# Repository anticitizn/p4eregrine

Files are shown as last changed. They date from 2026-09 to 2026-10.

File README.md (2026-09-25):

# P4eregrine
An all-in-one drone ESC, flight controller and video processor, powered by an ESP32 P4 in a 40x40 mm footprint.

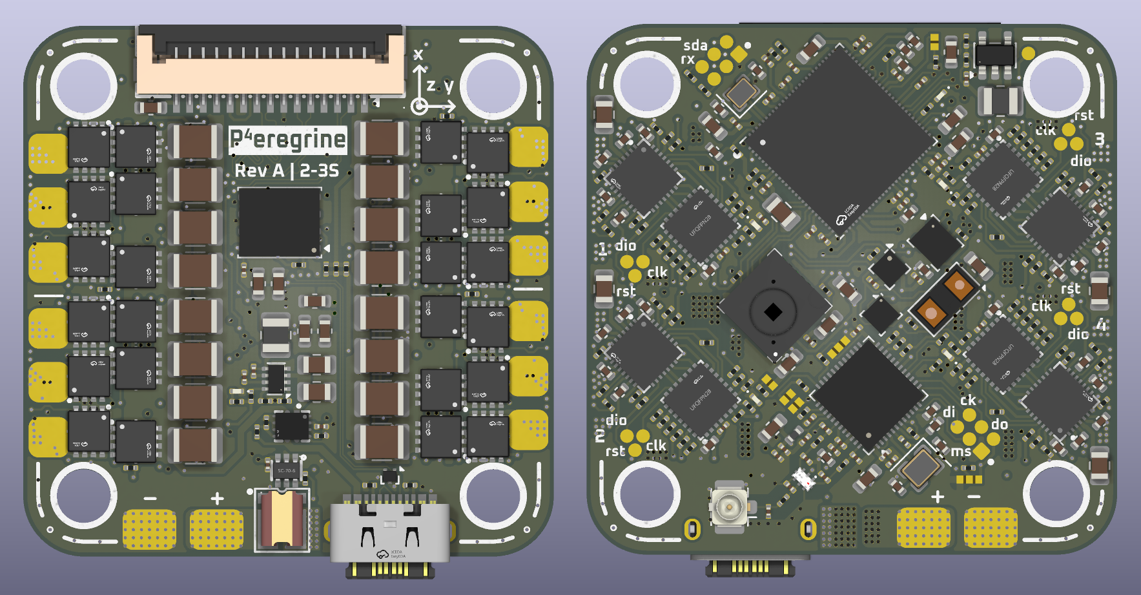
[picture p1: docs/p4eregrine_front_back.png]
Front and back PCB render


### Specifications
- 2S-3S (7-13 V) battery input
- 40x40 mm board size, 30.5x30.5 mm mounting holes
- ESP32 P4 flight computer and video processor
- ESP32 C5 for 2.4 GHz and 5 GHz Wi-Fi connectivity
- Raspberry Pi camera-compatible connector (MIPI-CSI)
- LSM6DSR IMU
- LIS2MDL magnetometer
- LPS22HB barometer
- VL53L1X time of flight sensor
- PMW3901MB optical flow sensor
- STM32G071GBU6 + DRV8328 for each ESC running AM32, hopefully capable of handling 15 A current per motor
- JMSL0302AU MOSFETs (the cheapest semi-reputable 3x3 package I could find with a lower than 3 mOhm RDS(on) when hot)
- TPS62933 buck converter for 3.3V power, capable of continuously supplying ~2.3 A
- Single high-side current measurement shunt for the entire board

### Stackup
6 layers, 1oz outer copper, 0.5 oz inner copper, 1.2 mm thick (JLC06121H-3313)
- L1: Mixed
- L2: GND
- L3: 3V3 plane + some signals
- L4: BAT plane + some signals
- L5: GND
- L6: Mixed

Filled and capped vias are a must, as the board makes extensive use of via-in-pad. All vias are 0.45/0.25 mm or bigger to avoid incurring extra fees from JLCPCB.

Schematics, layer images and BOM are available in `docs/`, Gerber files in `export/`.

### Software?
AM32 for the ESCs, custom firmware for the rest. I have most parts working on the previous prototype (ESP32 S3 with 8520 brushed motors)

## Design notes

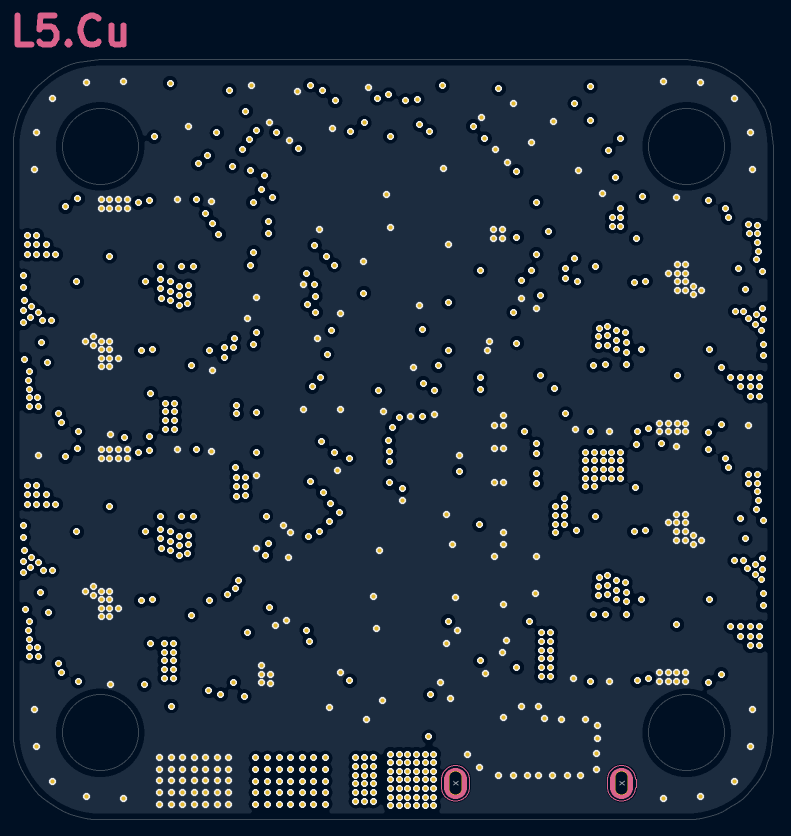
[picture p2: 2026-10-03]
docs/l5.png

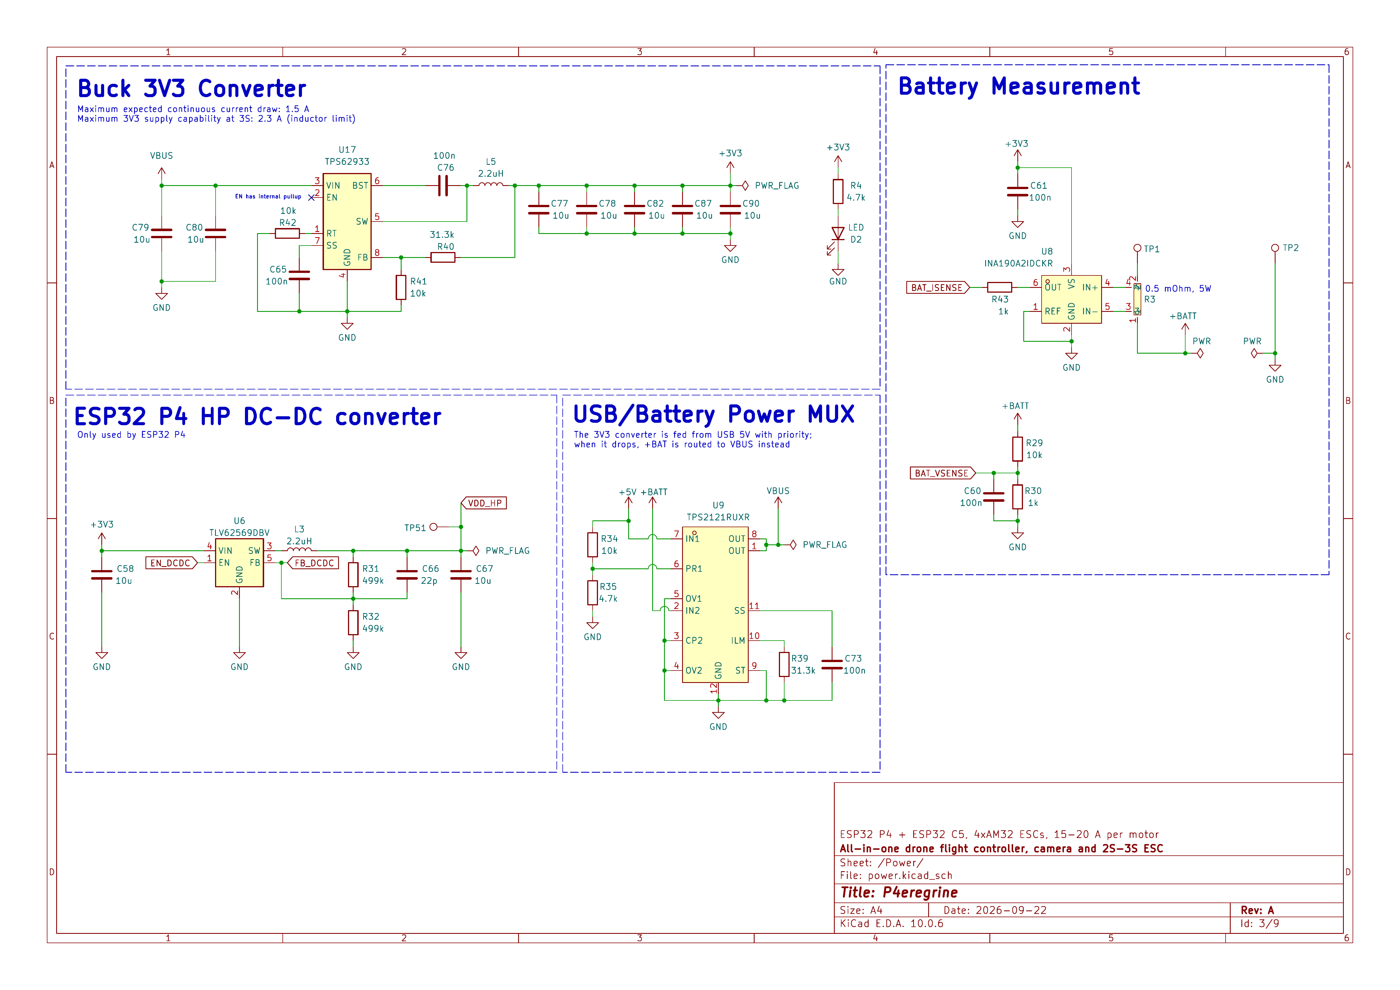
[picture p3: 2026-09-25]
docs/p4eregrine_rev_a-3.png

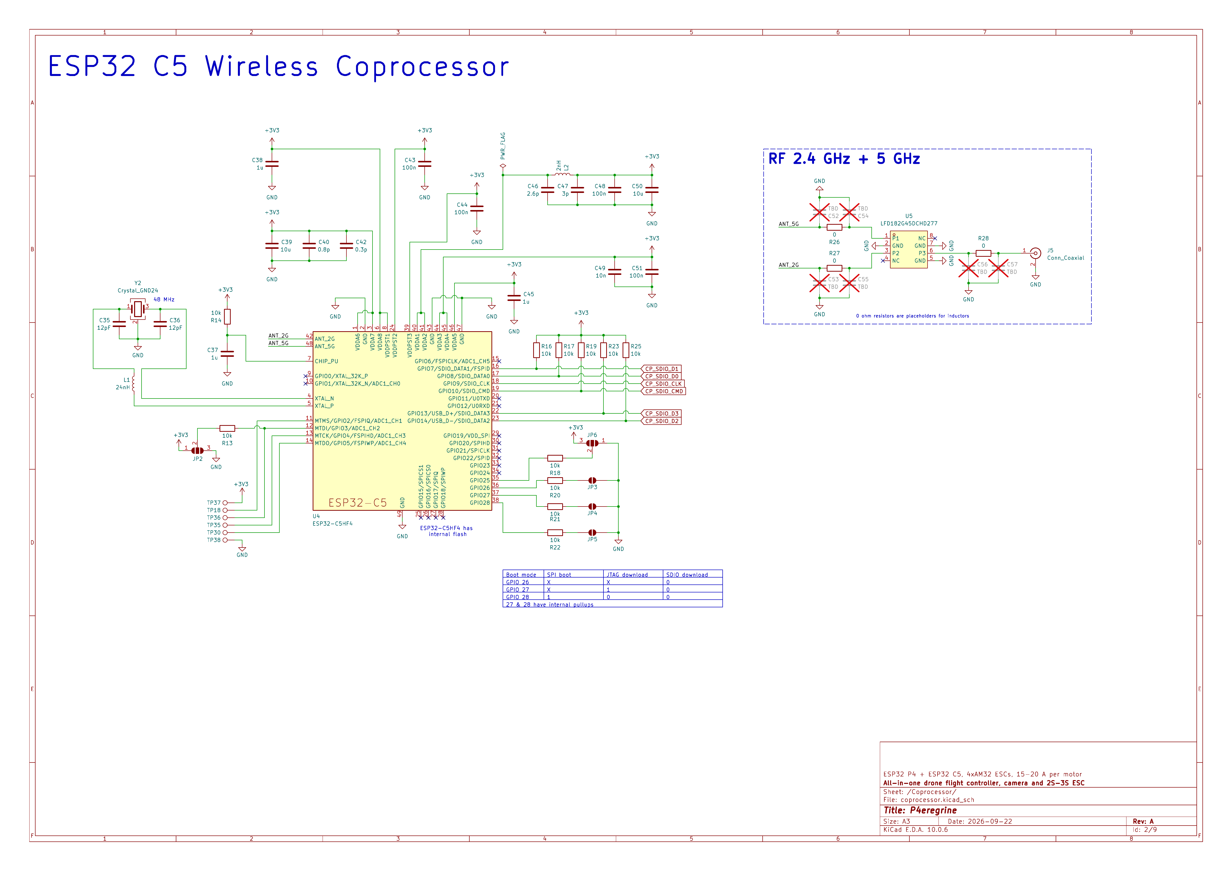
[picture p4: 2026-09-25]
docs/p4eregrine_rev_a-2.png

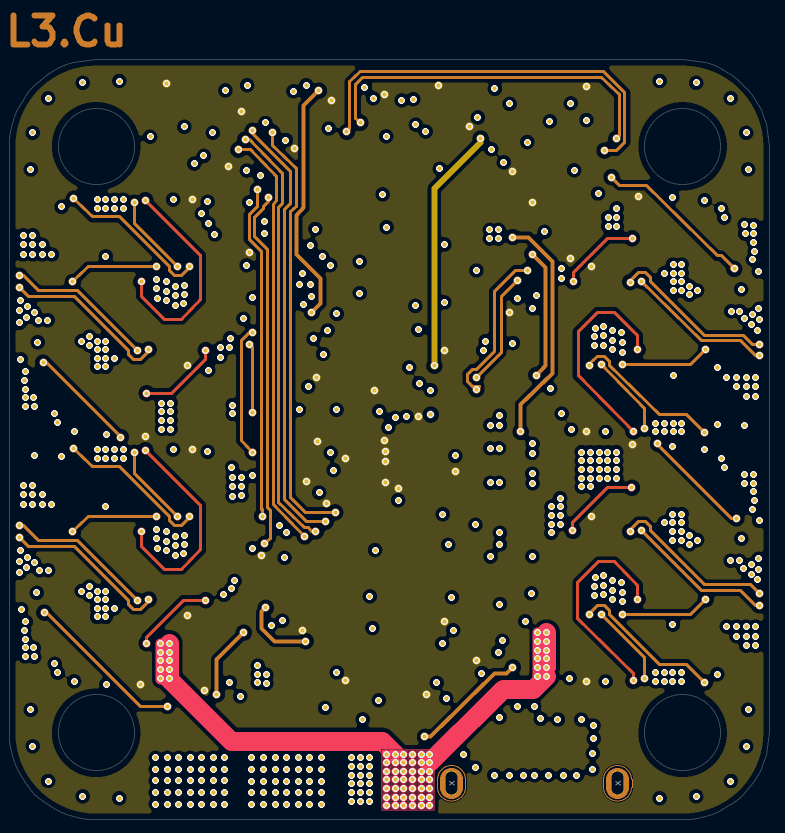
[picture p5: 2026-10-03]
docs/l3.png

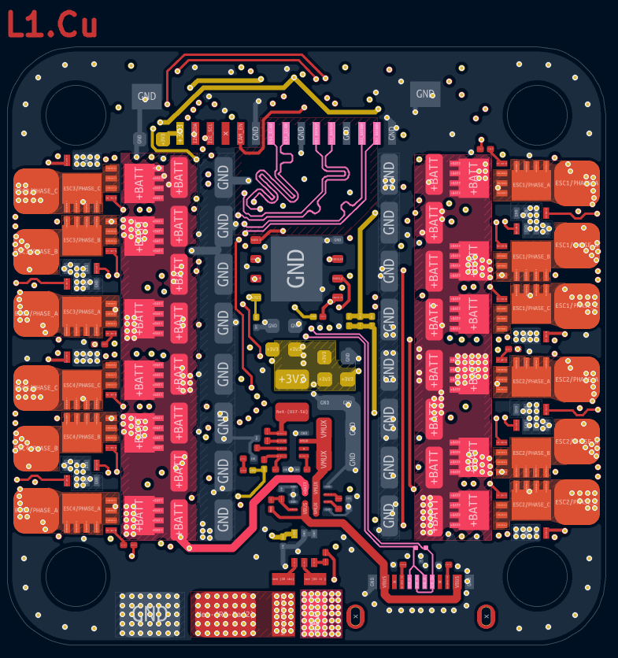
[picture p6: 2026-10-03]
docs/l1.png

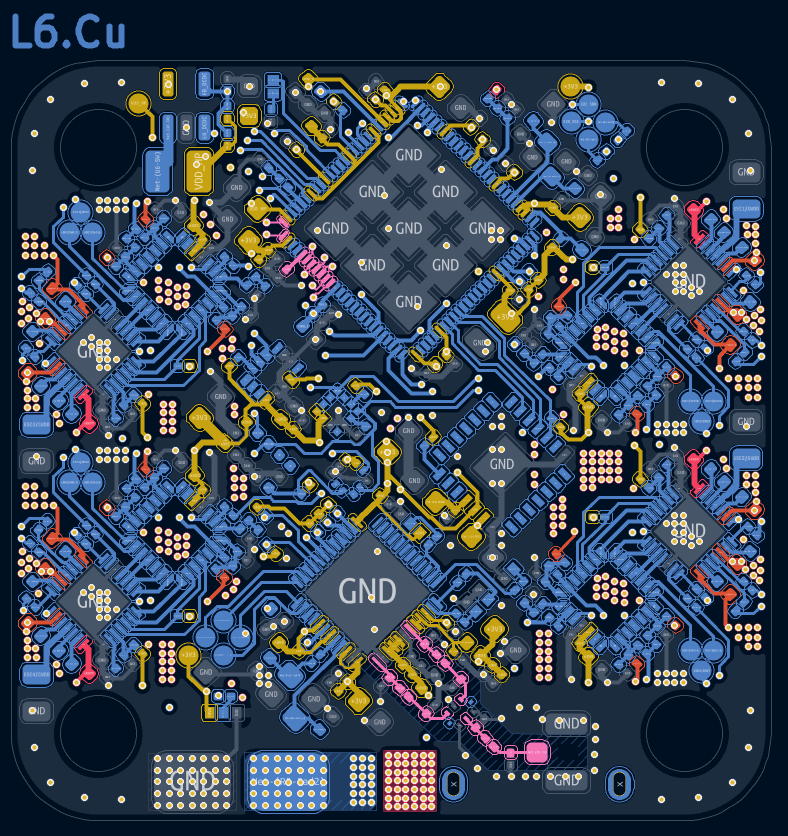
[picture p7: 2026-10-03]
docs/l6.png

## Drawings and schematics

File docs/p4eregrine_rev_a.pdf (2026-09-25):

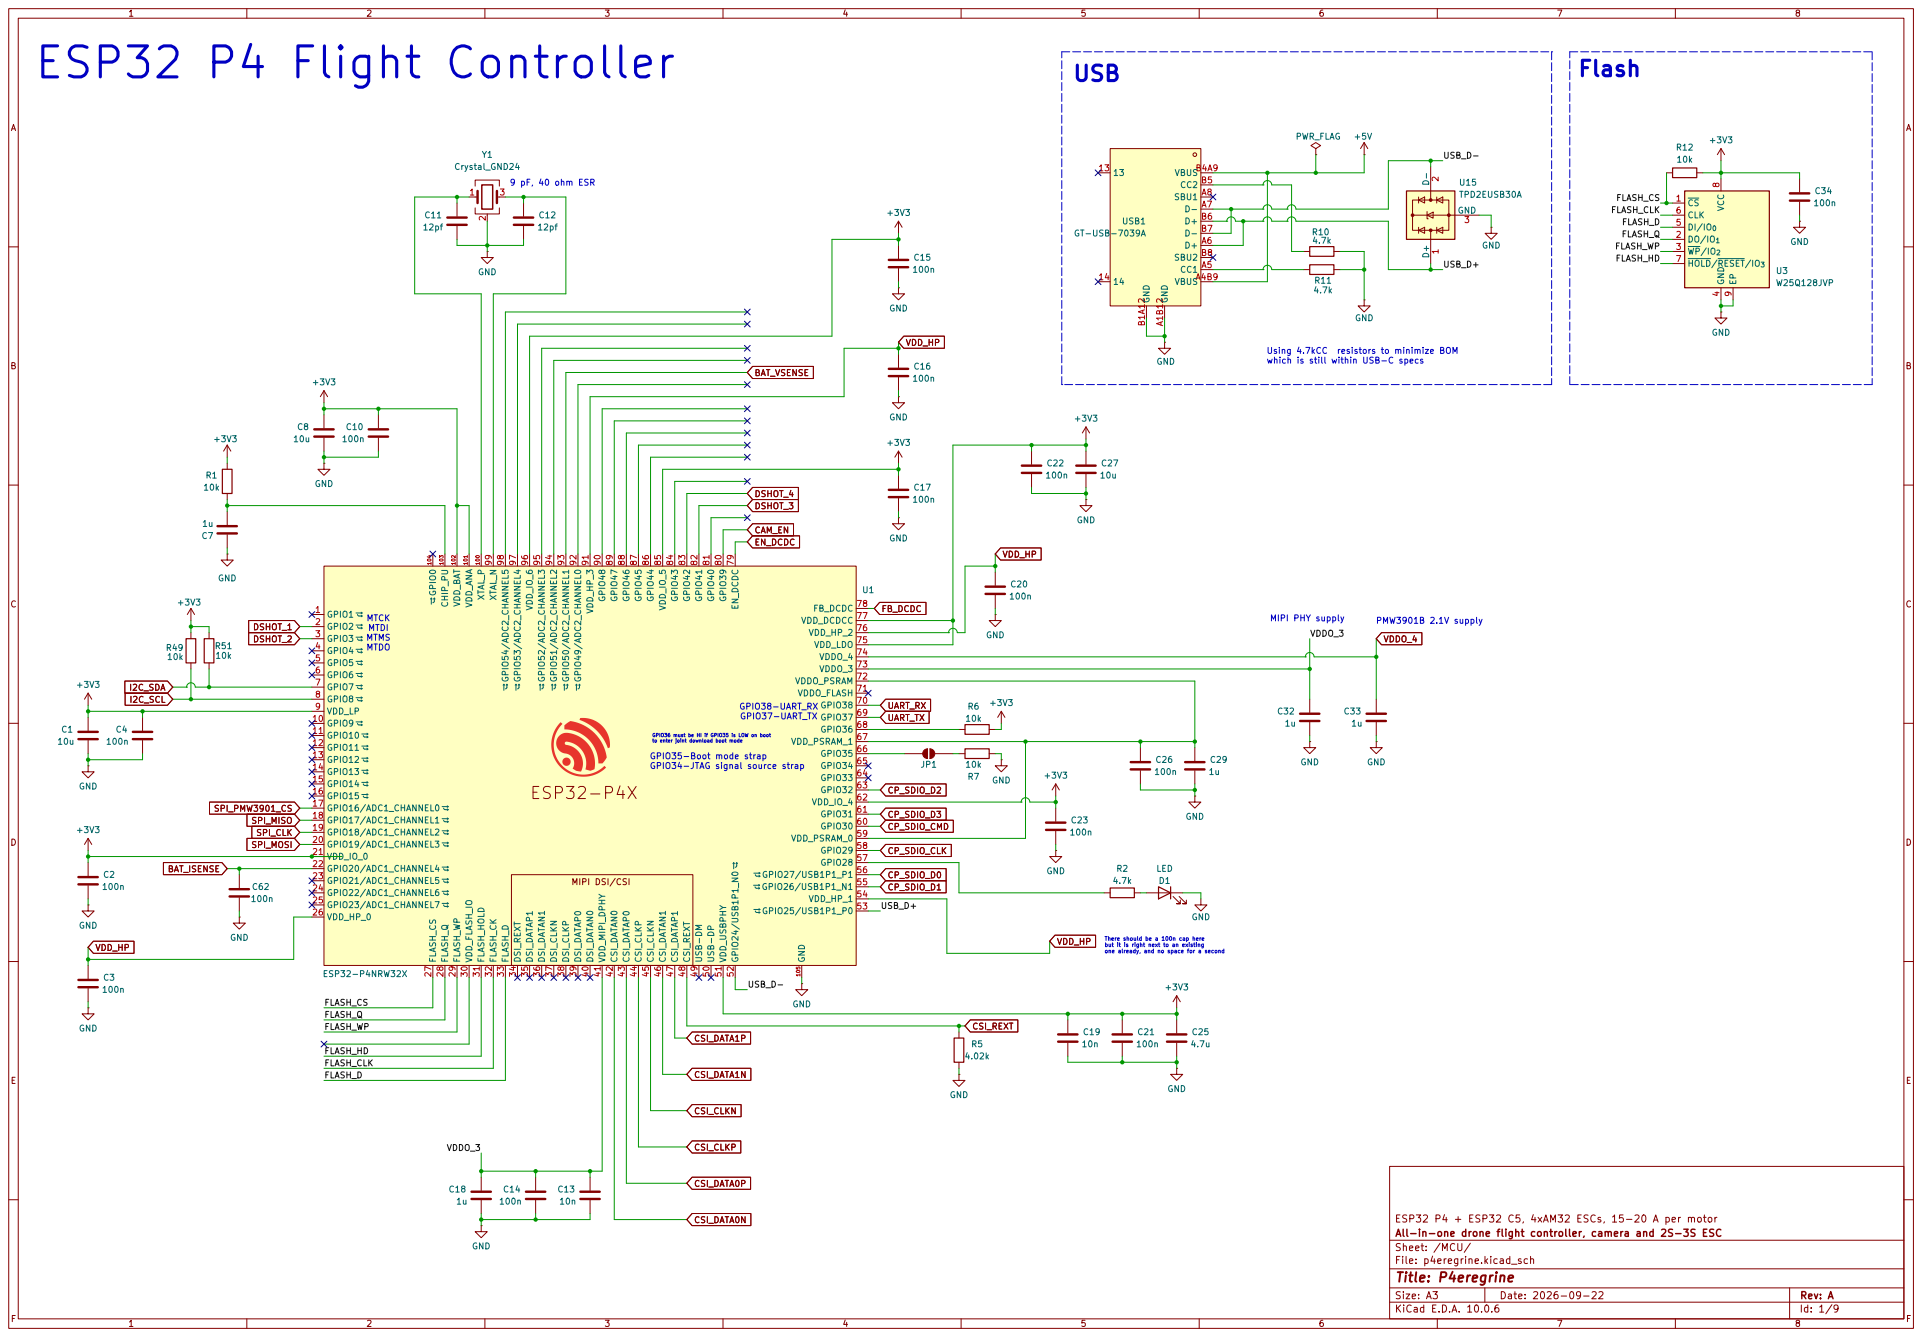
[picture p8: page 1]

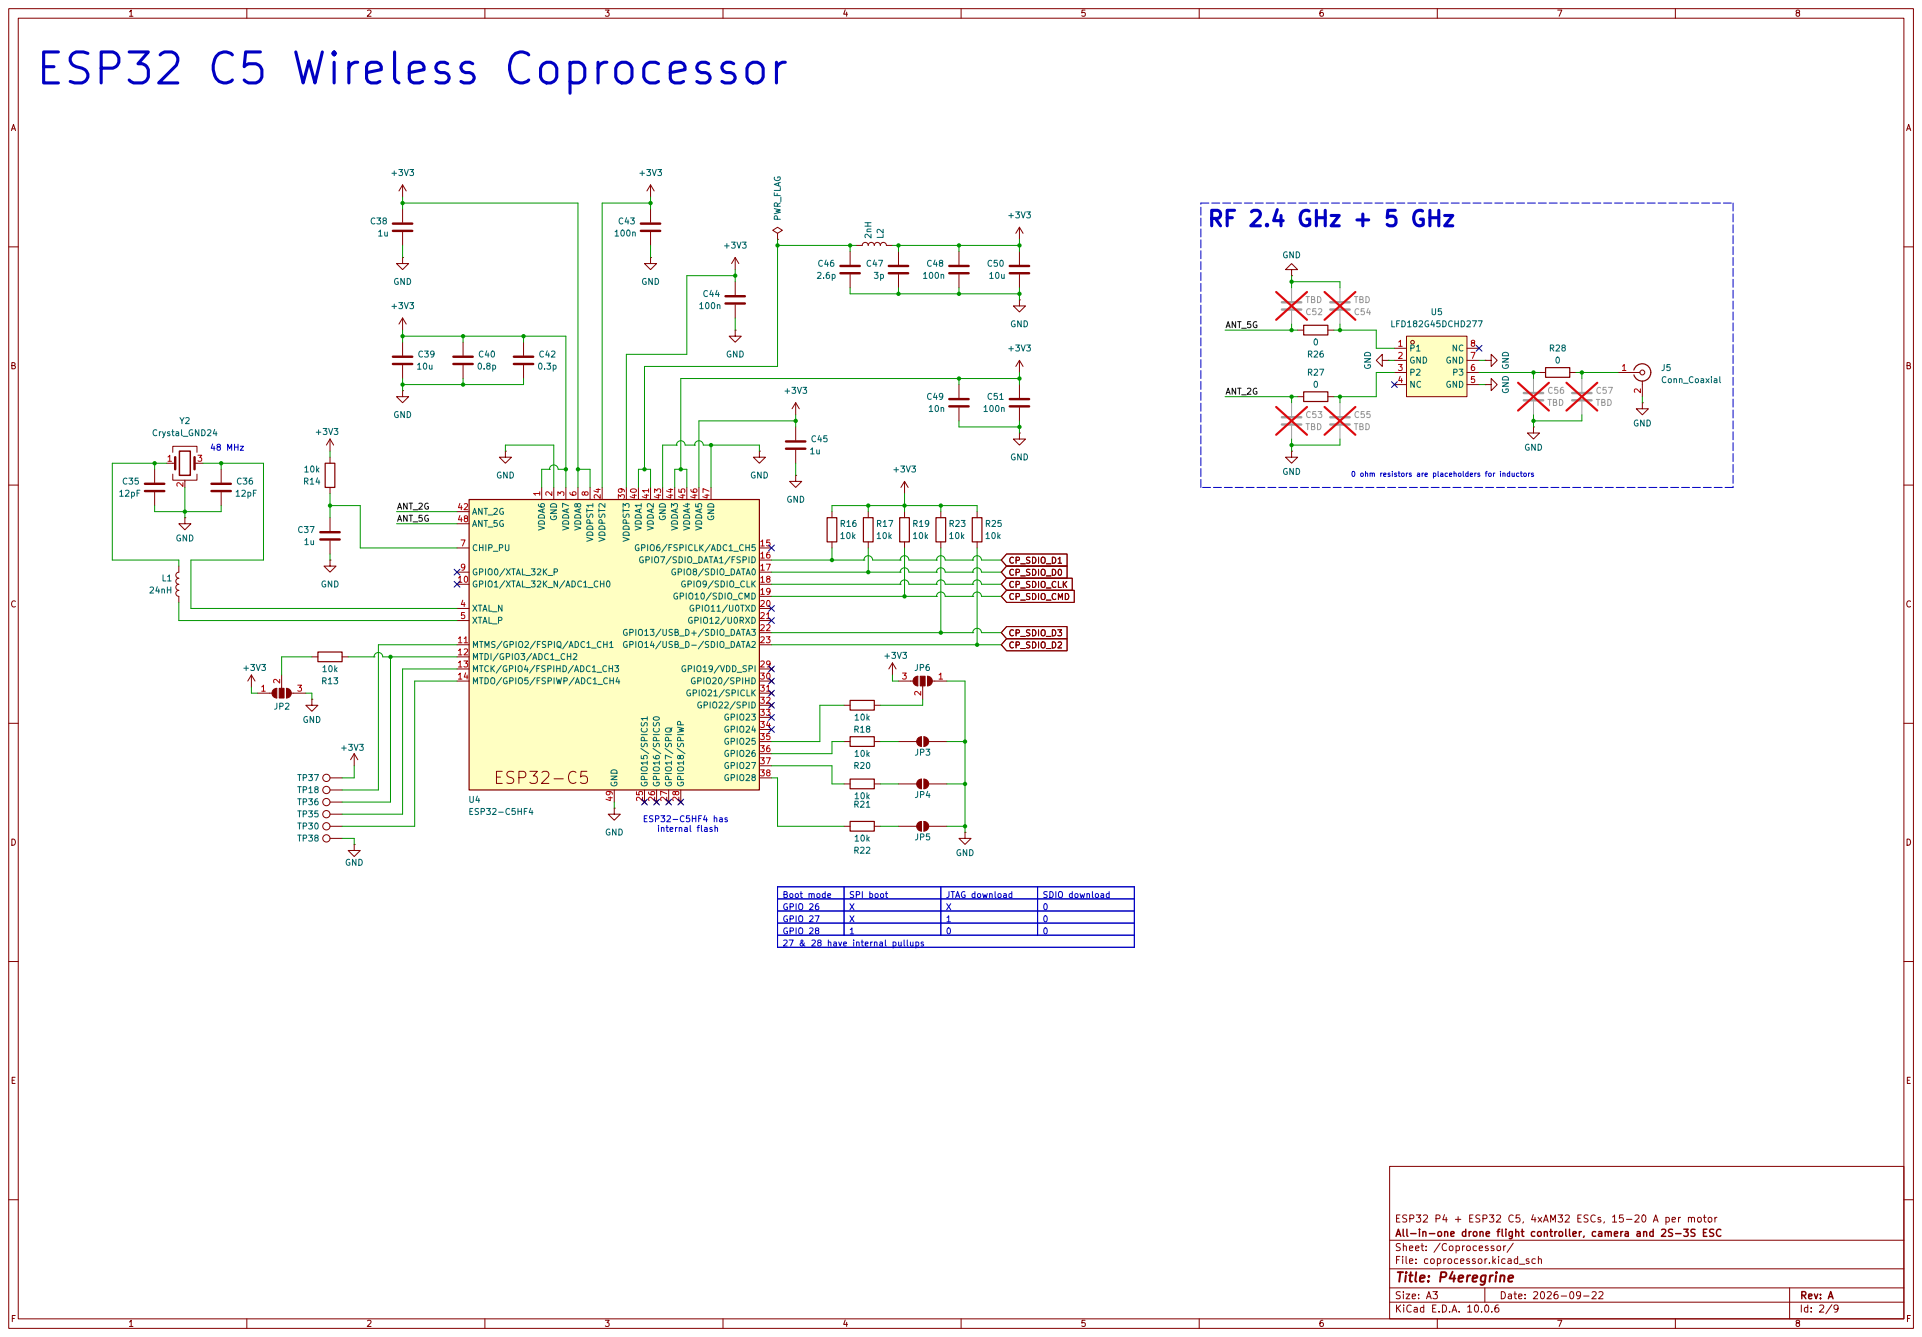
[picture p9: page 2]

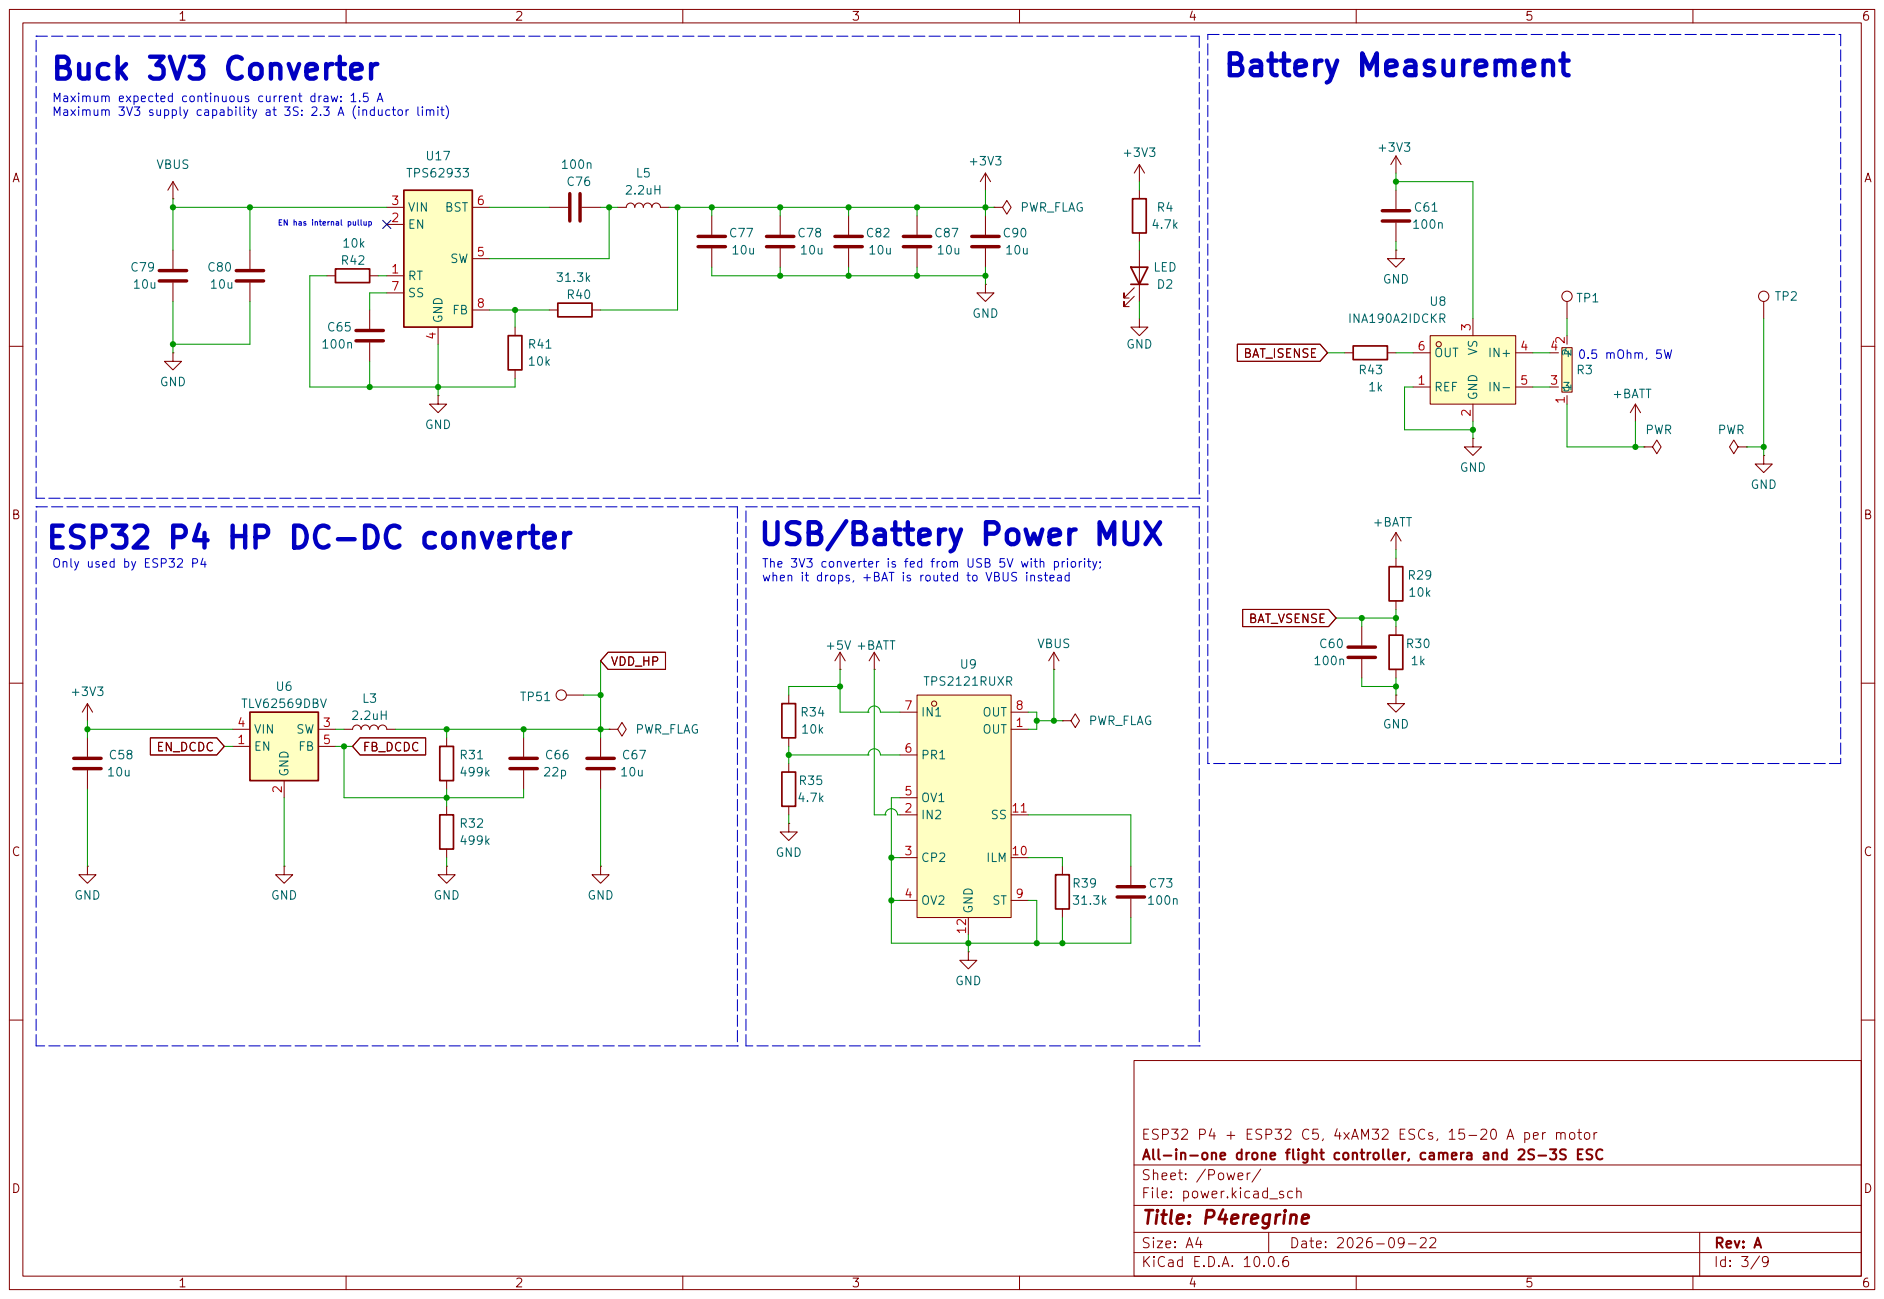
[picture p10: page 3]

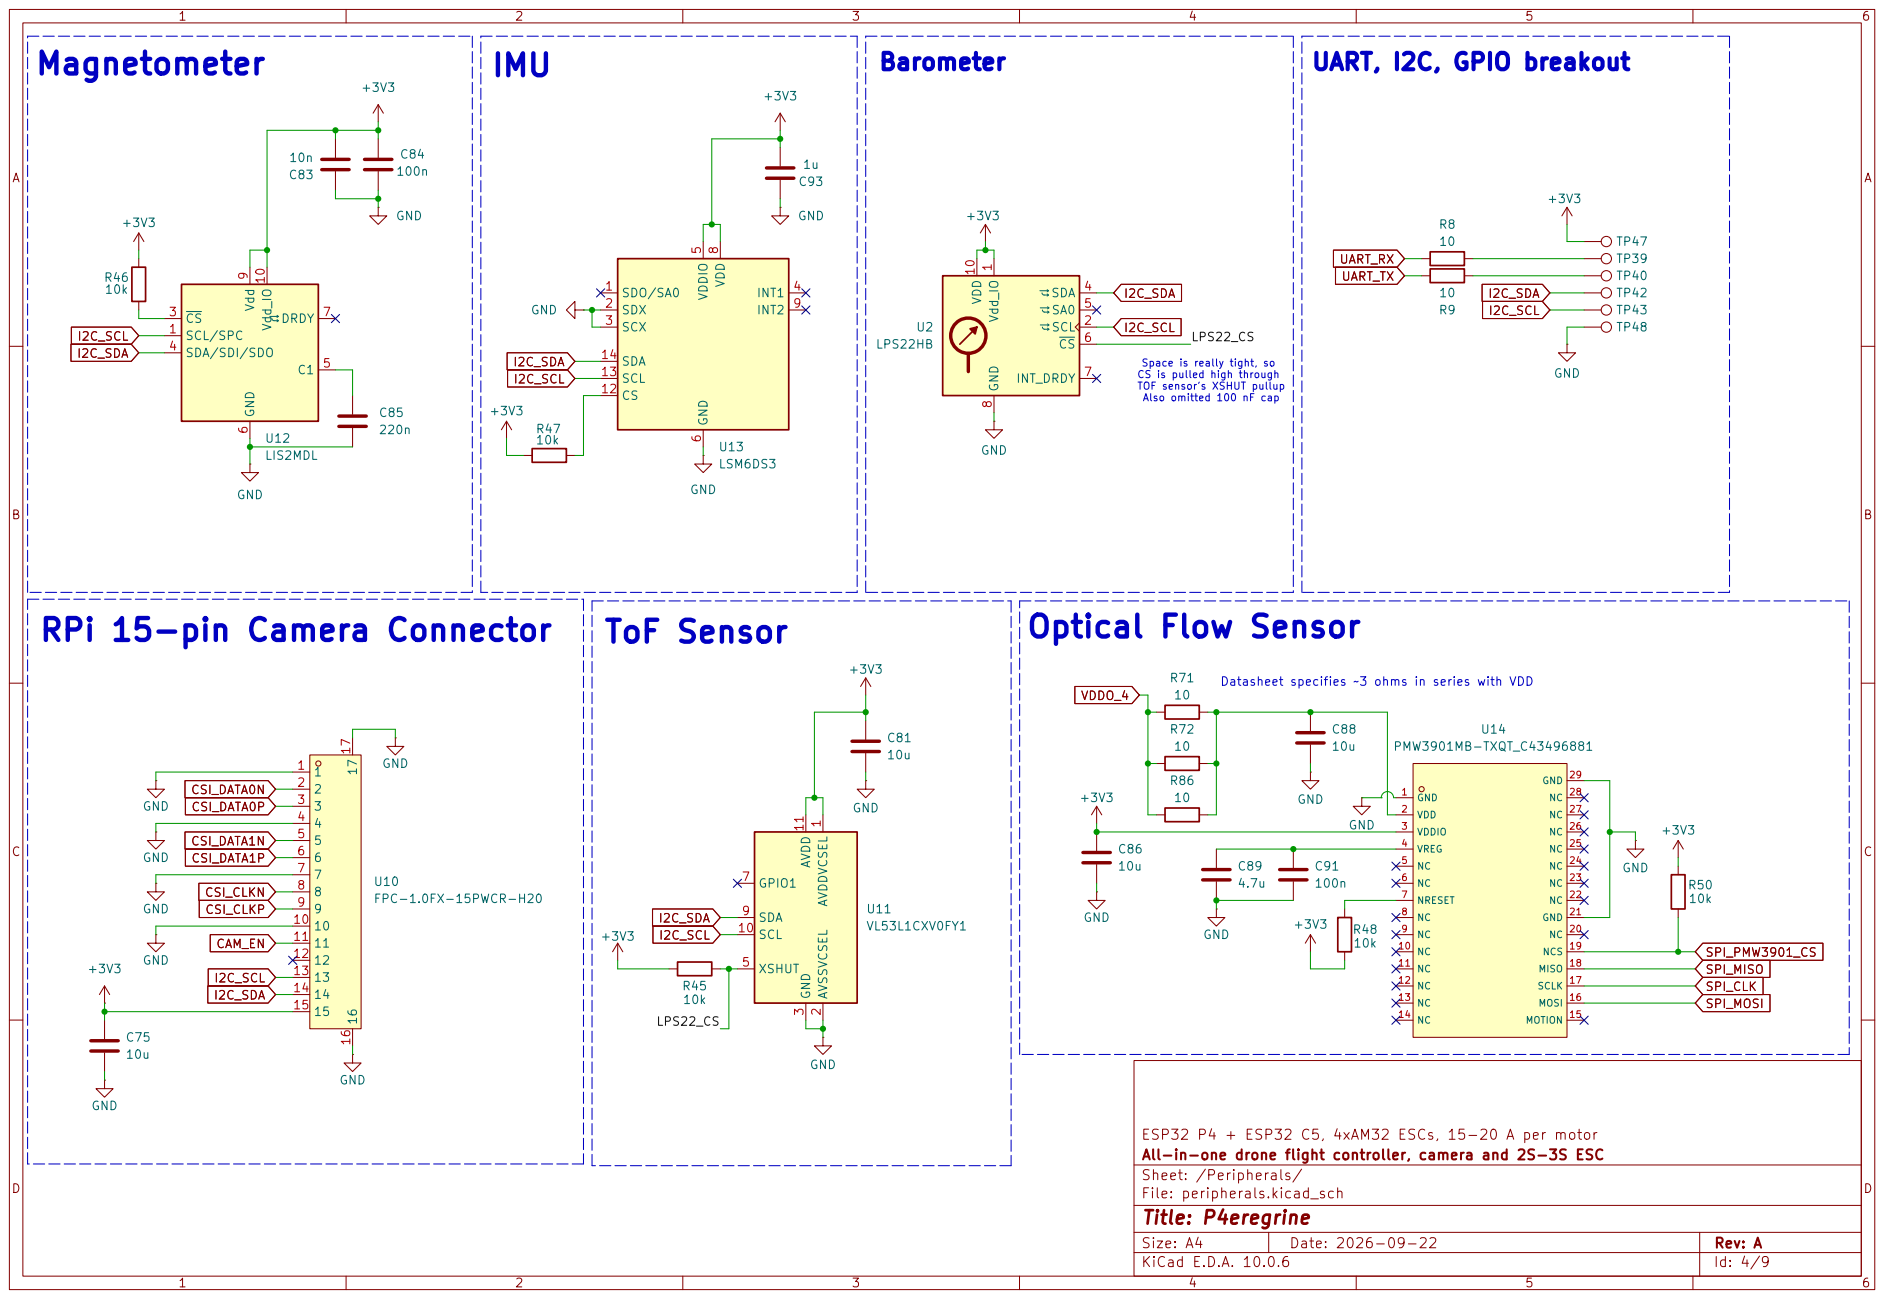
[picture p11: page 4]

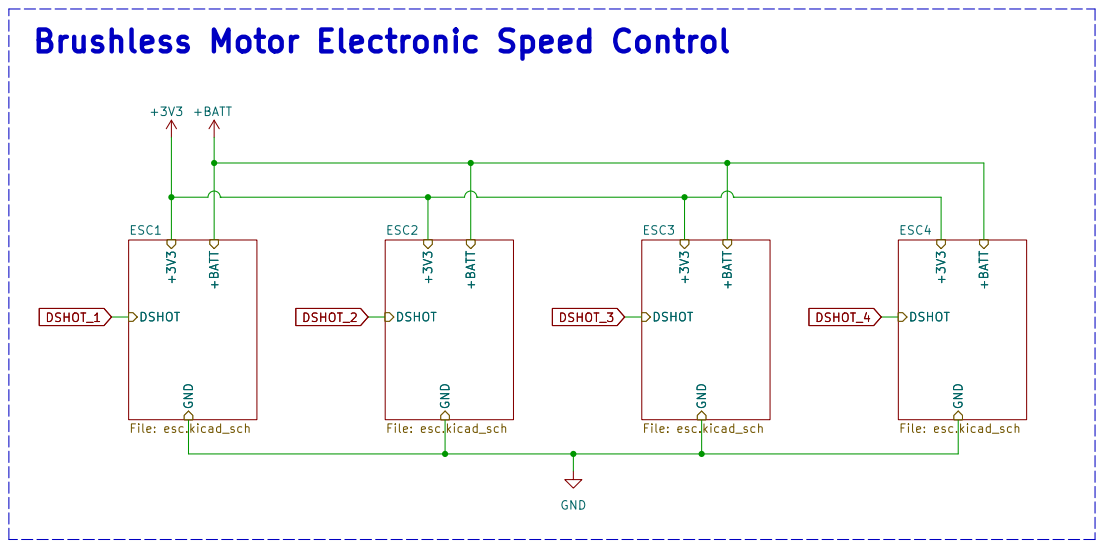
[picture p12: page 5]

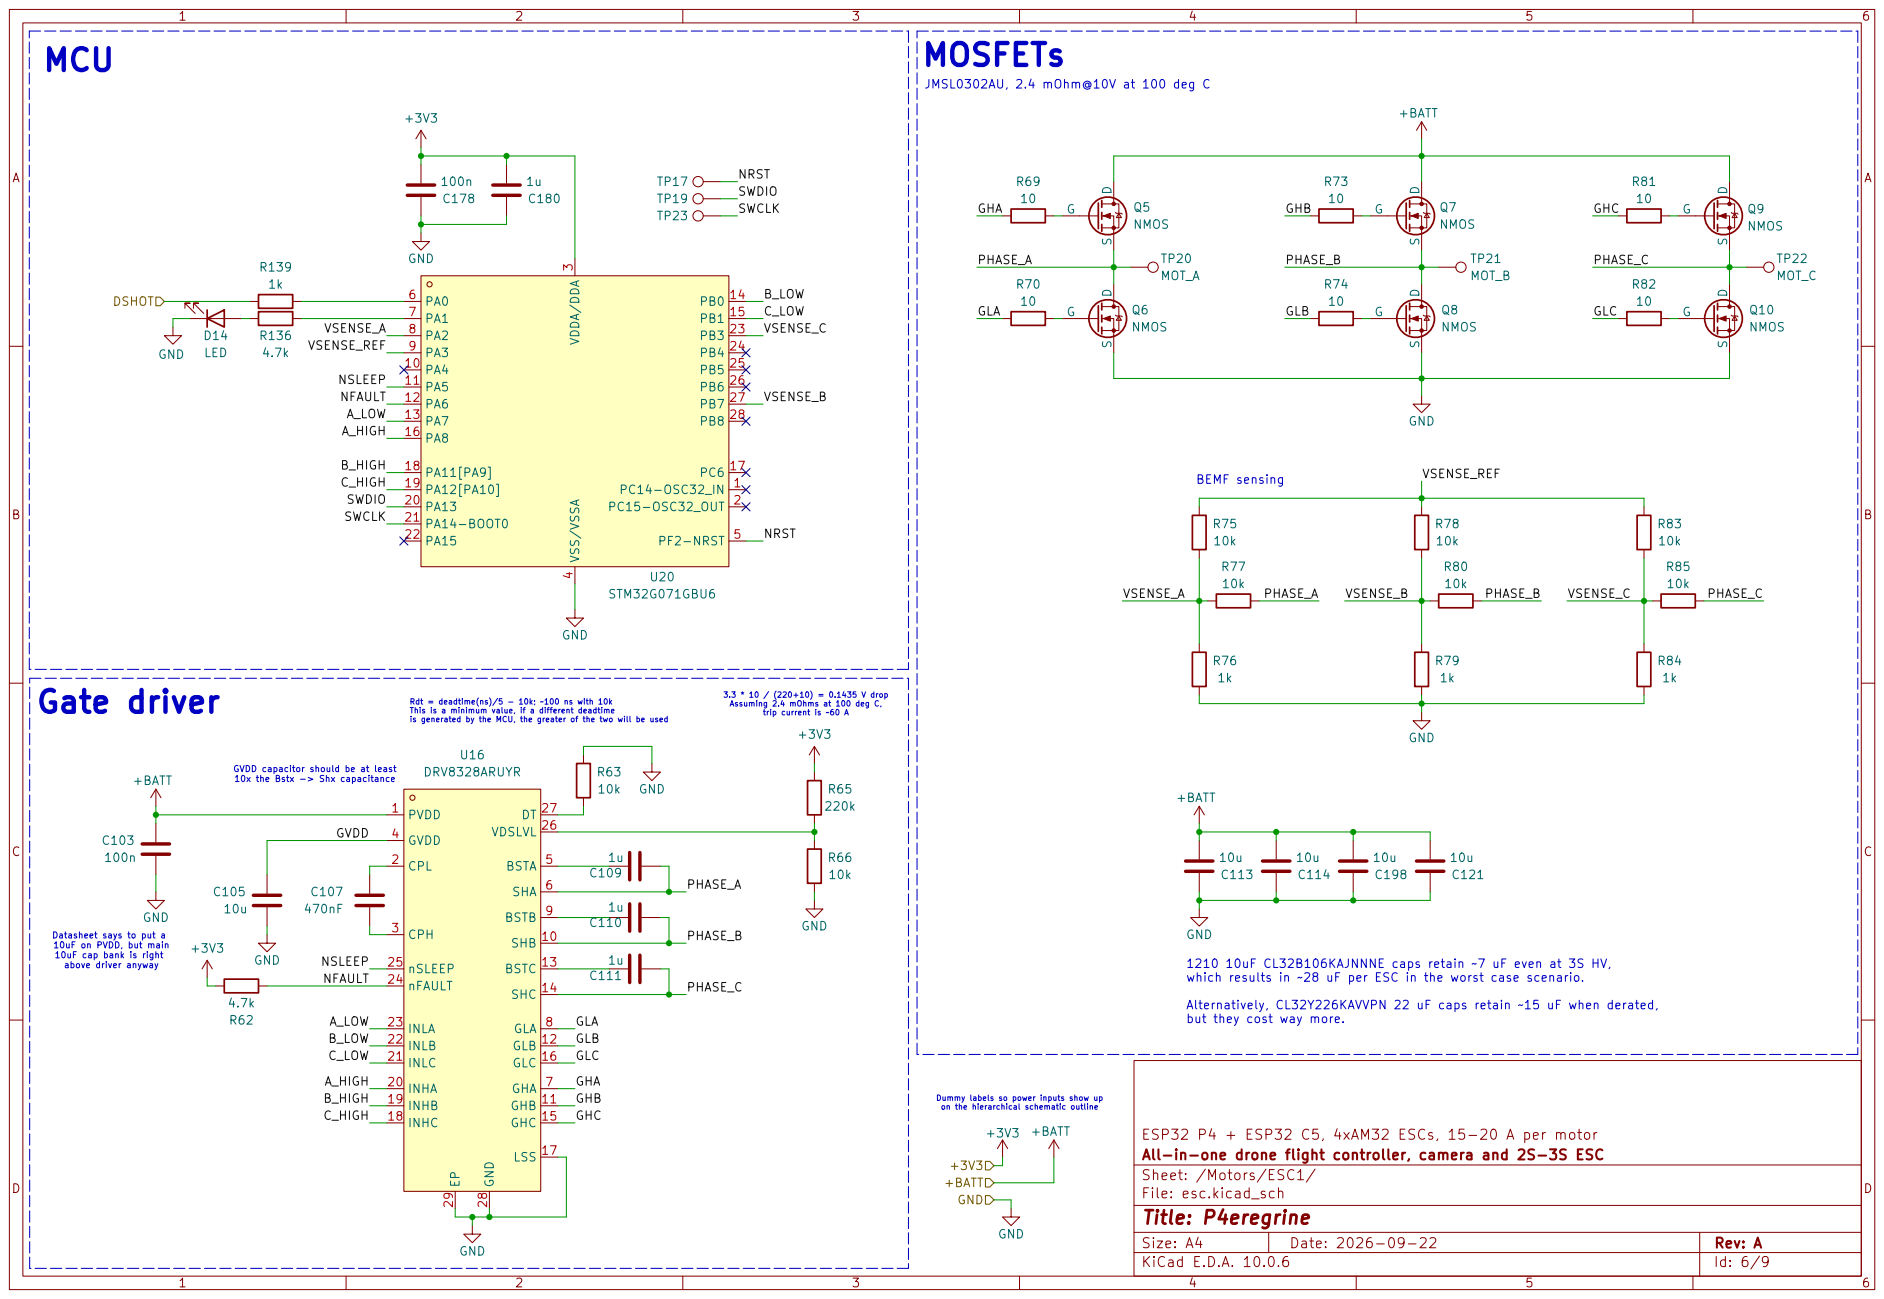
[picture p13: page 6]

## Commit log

2026-08-23 Ostensibly finish power sheet
    [espdrone.kicad_sch, motors.kicad_sch, peripherals.kicad_sch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]
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2026-08-25 Finish coprocessor power stage
    [coprocessor.kicad_sch]
2026-08-25 Add missing VDDA8 C5 supply
    [coprocessor.kicad_sch, power.kicad_sch]
2026-08-25 Ostensibly finish RF stage and add SDIO pullups
    [coprocessor.kicad_sch, espdrone.kicad_sch, peripherals.kicad_sch]
2026-08-25 Restore all functionality from v1
    [coprocessor.kicad_sch, espdrone.kicad_sch, motors.kicad_sch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]
2026-08-26 Add beginnings of ESC
    [bldc_motors.kicad_sch, coprocessor.kicad_sch, esc.kicad_sch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]
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2026-08-28 Reorder gate driver symbol and rearrange ESC
    [bldc_motors.kicad_sch, esc.kicad_sch, motors.kicad_sch]
2026-08-28 Fix LSS ground connection
    [esc.kicad_sch]
2026-08-28 Ostensibly finish ESC section
    [esc.kicad_sch]
2026-08-28 Add missing NFAULT pullup
    [esc.kicad_sch]
2026-08-28 Various little adjustments to ESC
    [bldc_motors.kicad_sch, esc.kicad_sch, motors.kicad_sch]
2026-08-28 Move ESCs to motors sheet
    [esc.kicad_sch, motors.kicad_sch, sensors.kicad_sch]
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2026-08-29 Improve power schematics readability
    [peripherals.kicad_sch, power.kicad_sch]
2026-08-29 Prettify most of the schematics
    [coprocessor.kicad_sch, esc.kicad_sch, espdrone.kicad_sch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]
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2026-08-29 Fix USB 5v -> VBUS error and some other small things
    [coprocessor.kicad_sch, esc.kicad_sch, espdrone.kicad_sch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]
2026-08-29 Replace all switches with jumpers and fix some footprints
    [coprocessor.kicad_sch, espdrone.kicad_sch, power.kicad_sch]
2026-08-29 Improve connectors and DC flyback diode
    [esc.kicad_sch, espdrone.kicad_pcb, espdrone.kicad_sch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]
2026-08-29 Reset schematic part number annotations
    [coprocessor.kicad_sch, esc.kicad_sch, espdrone.kicad_sch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]
2026-08-29 Resize lots of passives and replace current resistors with 4-wire shunts
    [coprocessor.kicad_sch, esc.kicad_sch, espdrone.kicad_pcb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]
2026-08-29 Minimize footprint size of most passives
    [esc.kicad_sch, peripherals.kicad_sch, power.kicad_sch]
2026-08-29 Fix the orientation of most resistor annotations
    [coprocessor.kicad_sch, esc.kicad_sch, espdrone.kicad_sch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]
2026-08-29 Fix ERC errors
    [coprocessor.kicad_sch, esc.kicad_sch, espdrone.kicad_sch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]
2026-08-29 Update PCB stackup and design rules
    [espdrone.kicad_pcb, espdrone.kicad_sch, power.kicad_sch]
2026-08-29 Fix USB-C connector footprint
    [espdrone.kicad_pcb, espdrone.kicad_sch]
2026-08-30 Remove a lot of test points
    [coprocessor.kicad_sch, esc.kicad_sch, espdrone.kicad_pcb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]
2026-08-30 Remove whole battery current shunt and replace MOSFETs with 3.3x3.3mm alternative
    [esc.kicad_sch, espdrone.kicad_pcb, motors.kicad_sch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]
2026-08-31 Improve some connector footprints
    [coprocessor.kicad_sch, esc.kicad_sch, espdrone.kicad_pcb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]
2026-08-31 Add custom solder jumper footprint, begin layouting
    [coprocessor.kicad_sch, esc.kicad_sch, espdrone.kicad_pcb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]
2026-08-31 Reduce amounts of broken out GPIOs
    [espdrone.kicad_pcb, espdrone.kicad_sch]
2026-08-31 Sort of workable P4 layout
    [espdrone.kicad_pcb]
2026-08-31 Preliminary C5 layout done
    [coprocessor.kicad_sch, esc.kicad_sch, espdrone.kicad_pcb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]
2026-08-31 Do local layout of power sheet
    [espdrone.kicad_pcb, power.kicad_sch]
2026-08-31 Get rid of 1.8V LDO and use P4 VDDO4 instead
    [espdrone.kicad_pcb, espdrone.kicad_sch, peripherals.kicad_sch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]
2026-09-01 Do some ESC layouting
    [esc.kicad_sch, espdrone.kicad_pcb]
2026-09-01 Progress on bridge layout
    [espdrone.kicad_pcb]
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2026-09-01 ESC mostly done apart from STM routing
    [esc.kicad_sch, espdrone.kicad_pcb]
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2026-09-01 Ostensibly finish ESC routing
    [espdrone.kicad_pcb, espdrone.kicad_sch, motors.kicad_sch]
2026-09-01 Add dimensions for MOSFET rearranging
    [espdrone.kicad_pcb]
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2026-09-01 Initial ESC bulk capacitance placement
    [espdrone.kicad_pcb]
2026-09-02 Done routing for first ESC version
    [esc.kicad_sch, espdrone.kicad_pcb]
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2026-09-02 Start work on alternative ESC routing
    [espdrone.kicad_pcb]
2026-09-02 Improve ESC V2 routing
    [esc.kicad_sch, espdrone.kicad_pcb]
2026-09-02 Finish initial ESC V2 layout
    [esc.kicad_sch, espdrone.kicad_pcb]
2026-09-02 Improve capacitor bank connection
    [espdrone.kicad_pcb]
2026-09-03 Add 3 more caps and remove floating islands in ESC V2
    [esc.kicad_sch, espdrone.kicad_pcb]
2026-09-03 Add missing VREF resistor connection
    [espdrone.kicad_pcb]
2026-09-03 Decrease clearance of ground planes to 0.2mm
    [espdrone.kicad_pcb]
2026-09-03 Repeat ESC layout and route out LSS measurement signal to gate driver
    [espdrone.kicad_pcb]
2026-09-03 Group each ESC properly and add silkscreen
    [espdrone.kicad_pcb]
2026-09-03 Fix ESC groups
    [espdrone.kicad_pcb]
2026-09-03 Update all ESC footprints
    [espdrone.kicad_pcb]
2026-09-03 Move ESCs to board cutout
    [espdrone.kicad_pcb]
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2026-09-04 Fix DC motor MOSFET footprint
    [espdrone.kicad_pcb, motors.kicad_sch, peripherals.kicad_sch]
2026-09-04 Connect C5 to P4
    [coprocessor.kicad_sch, espdrone.kicad_pcb]
2026-09-04 Commence laying out mirrored ESC
    [espdrone.kicad_pcb]
2026-09-05 Finish routing mirrored ESC
    [espdrone.kicad_pcb]
2026-09-05 Improve mirrored ESC routing
    [espdrone.kicad_pcb]
2026-09-05 Recover lost ESP assembly
    [espdrone.kicad_pcb]
2026-09-05 Fix mirrored and unmirrored ESC conflicts
    [espdrone.kicad_pcb]
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2026-09-06 Place MCU and coprocessor on bottom layer
    [espdrone.kicad_pcb]
2026-09-06 Make buck-boost layout more compact
    [espdrone.kicad_pcb]
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2026-09-06 Remove external SPI connections and switch voltage measurement from VBUS to +BAT
    [espdrone.kicad_pcb, espdrone.kicad_sch, motors.kicad_sch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]
2026-09-06 Fix botched NRST tracks on two ESCs
    [espdrone.kicad_pcb]
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2026-09-07 Fix a bunch of misplaced footprints and traces in 2 ESCs
    [espdrone.kicad_pcb]
2026-09-07 Fix a lot of ESC routing errors and remove unused annular rings on all vias
    [espdrone.kicad_pcb]
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2026-09-08 Minimize passive footprints again and switch ESC mcu to smaller footprint
    [coprocessor.kicad_sch, esc.kicad_sch, espdrone.kicad_pcb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]
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2026-09-14 Fix isense track on ESCs going outside board edges
    [espdrone.kicad_pcb]
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2026-09-14 Start rerouting ESC to account for 0.5mm spacing between MCU and gate driver..
    [espdrone.kicad_pcb]
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2026-09-17 Add missing C phase BEMF GND connections
    [espdrone.kicad_pcb]
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2026-09-18 Replace generic GPIOs with UART on the P4 breakout
    [espdrone.kicad_pcb, espdrone.kicad_sch, peripherals.kicad_sch]
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2026-09-21 Fix all DRC errors and ignore copper intersection ones
    [espdrone.kicad_pcb]
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2026-09-21 Fix BEMF comparator pinout
    [coprocessor.kicad_sch, esc.kicad_sch, espdrone.kicad_pcb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]
2026-09-21 Switch to 2.2 uH 1008 inductor for both DCDC converters
    [coprocessor.kicad_sch, esc.kicad_sch, espdrone.kicad_pcb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]
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2026-09-24 Fix stackup settings in kicad
    [p4eregrine.kicad_pcb]
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2026-09-24 Fix GND copper pour priority
    [p4eregrine.kicad_pcb]
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2026-09-24 Add BAT_ISENSE filtering cap and improve 3v3 plane continuity
    [p4eregrine.kicad_pcb, p4eregrine.kicad_sch]
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2026-09-25 Fix some silkscreen overlapping copper issues
    [p4eregrine.kicad_pcb, p4eregrine.kicad_sch]
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2026-09-25 Get rid of layer text used for screens
    [p4eregrine.kicad_pcb]
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2026-09-27 Move 0201 gate resistors away from mounting holes
    [p4eregrine.kicad_pcb]
2026-09-27 Move 0201 gate resistors from between the motor pads
    [p4eregrine.kicad_pcb]
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2026-09-28 Fix FPC socket 3D model position offset
    [p4eregrine.kicad_pcb]
2026-09-28 Only use samsung caps for 10uf low voltage
    [coprocessor.kicad_sch, p4eregrine.kicad_pcb, p4eregrine.kicad_sch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]
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2026-10-03 Fix CP_SDIO_CLK label polarity
    [coprocessor.kicad_sch, p4eregrine.kicad_sch]
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2026-10-14 Get rid of 4.7uf caps and add missing MPNs to BOM
2026-10-14 Fix some typos in comments and BOM description
